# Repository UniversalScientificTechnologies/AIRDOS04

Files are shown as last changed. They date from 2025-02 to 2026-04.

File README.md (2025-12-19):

# AIRDOS04 - Specialized Cosmic Radiation Dosimeter for Airliners

AIRDOS04

The upgraded version of [AIRDOS02](https://github.com/UniversalScientificTechnologies/AIRDOS02) airborne detector. The instrument is designed primarily for the dosimetry of cabin crew and flight attendants of commercial flights. A detailed description of the use is in the [user manual](https://docs.dos.ust.cz/airdos/AIRDOS04).

## Design features 

  - Rechargeable accumulators integrated with data storage in the hot-swap module called [BATDATUNIT01](https://docs.dos.ust.cz/airdos/BATDATUNIT01)
    - The changeable module allows new possible features in the future, like GNSS-based position logging with a revised module 
  - One month of continuous logging for a single accumulator charge
  - Easy measurement activation by insertion of the BATDATUNIT module
  - Data download without special software (Mass storage media)
  - Continuously incrementing time marks (Unique logging time from every measurement) 

## Where to get it?

Purchase AIRDOS04, the open-source device designed for versatility, from [Universal Scientific Technologies s.r.o.](https://www.ust.cz). For sales inquiries, contact sale@ust.cz. Developed and maintained by UST, it comes with full commercial availability and dedicated technical support. The device is released under the GPLv3 license.

## Technical parameters

  * Silicon PIN diode detector with 44 mm³ detection volume
  * The effective number of energy channels is 886 ± 3
  * Deposited energy ranges from 36 keV to 7 MeV
  * Energy measurement resolution 15 ± 2 keV
  * Service interface:  USB-C connector (charging and data download)
  * Energy source: 18650 Li-ion cells conforms with [≤ 100 Wh / 2g restrictions](https://www.iata.org/contentassets/6fea26dd84d24b26a7a1fd5788561d6e/passenger-lithium-battery.pdf)
  * Radiation spectra integration time 10 s
  * Maintenance interval (data download, battery recharge)  30 days
  * Maintenance duration under 5 minutes
  * Approx size LxWxH 166 mm x 107 mm x 57 mm (two  of these should fit into the Aircraft printed manual bay)
  * Weight is 0.88 kg (With five accumulator cells in [BATDATUNIT01](https://github.com/mlab-modules/BATDATUNIT01))
  * Environmental operational conditions
    * Device protection: IP30 rating (fully assembled)
    * Operation temperature range: 0°C to 50°C (32°F to 122°F)
    * Operation humidity conditions: non-condensing, 20% to 80% RH

## Example data

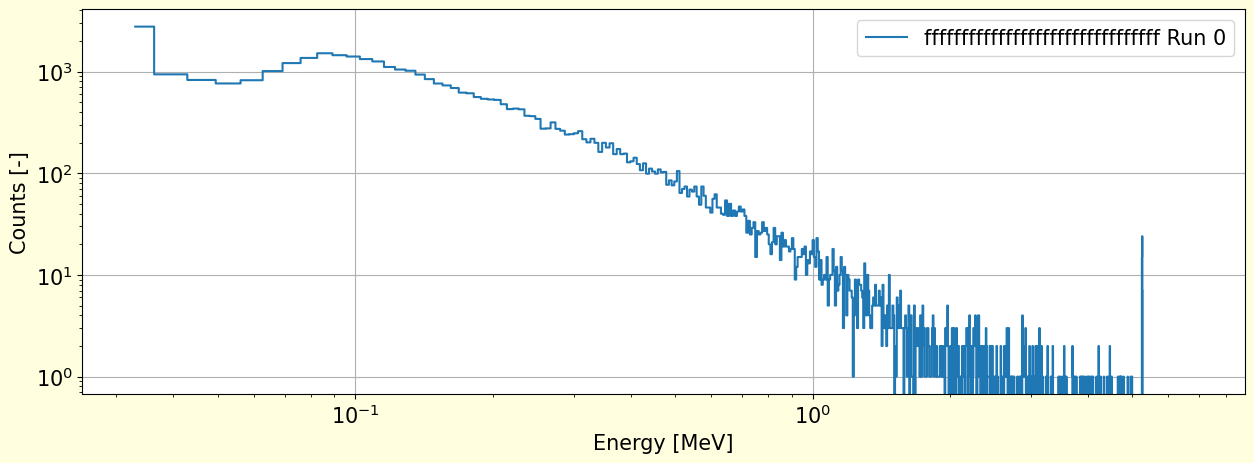
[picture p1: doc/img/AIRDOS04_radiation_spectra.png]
AIRDOS04 radiation spectra measurement


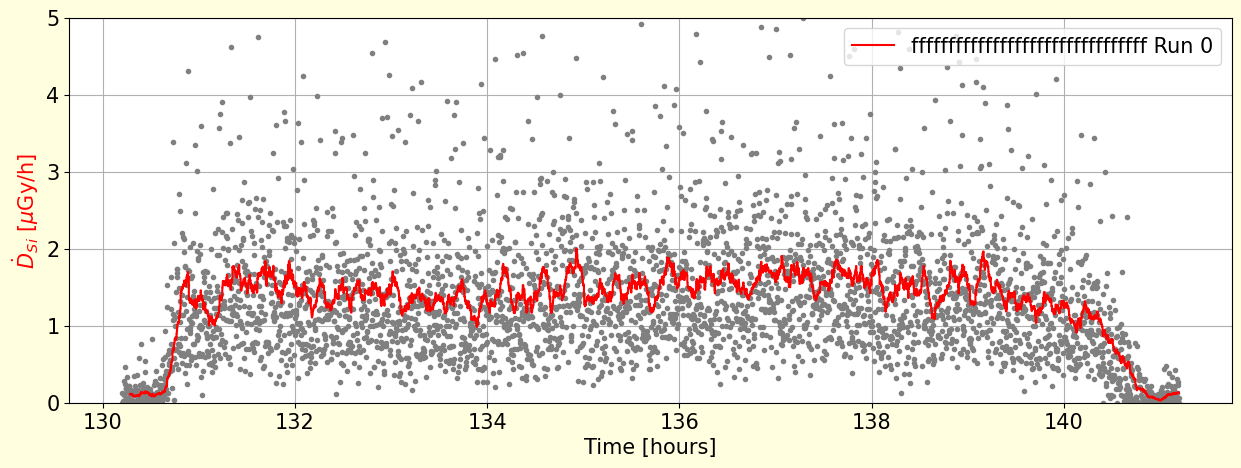
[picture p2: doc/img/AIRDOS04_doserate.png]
AIRDOS04 flight dose rate measurement


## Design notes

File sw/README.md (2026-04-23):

## airdoscontrol - AIRDOS04 command line utility

A utility designed to control the AIRDOS04 dosimeter from the [Unix command line](https://ubuntu.com/tutorials/command-line-for-beginners#1-overview). The  generic usage is the following

    sudo ./airdoscontrol [command] [options]

The airdos control is tested on the Ubuntu Linux distribution. However, it should work on any Unix-like OS like MacOS for example, although the installation procedure may differ in details. 

### Installation and prerequisites 

Download and save the [airdoscontrol](https://raw.githubusercontent.com/UniversalScientificTechnologies/AIRDOS04/AIRDOS04A/sw/airdoscontrol) somewhere in your Linux computer. Then make it executable by setting the executable flag on the downloaded file.   

    chmod u+x airdoscontrol

The airdos control uses [hidapi library](https://pypi.org/project/hidapi/) to communicate with AIRDOS, please check that hidapi is installed or install it by 

    sudo python3 -m pip install hidapi 

In case you do not want tu use [sudo](https://www.howtoforge.com/sudo-beginners-guide/) to run airdoscontrol every time, the utility needs correct [system access rights](https://linuxconfig.org/tutorial-on-how-to-write-basic-udev-rules-in-linux) to the hid device. To fix that create the file  `/etc/udev/rules.d/99-batdatunit.rules` in your Linux system with the following content:

```
ACTION=="add", SUBSYSTEM=="usb", ATTR{idVendor}=="0403", ATTR{idProduct}=="6030", OPTIONS+="ignore_device"
KERNEL=="hidraw*", ATTRS{idVendor}=="0403", MODE="6030", GROUP="plugdev"
SUBSYSTEM=="usb", ATTRS{idVendor}=="1209", ATTRS{idProduct}=="7aa0", GROUP="plugdev", MODE="0660"
SUBSYSTEM=="hidraw", ATTRS{idVendor}=="1209", ATTRS{idProduct}=="7aa0", GROUP="plugdev", MODE="0666"
```
Then use `sudo udevadm control --reload-rules && sudo udevadm trigger` command to update udev access rights. 

The user also needs to be a `plugdev` system group member. e.g. `sudo usermod -a -G plugdev $USER`

### Usage

Connect the AIRDOS04 to the computer using the USB-C to USB-A cable. NOTE: The BATDATUNIT01 should be inserted in AIRDOS04 for USB communication. 

#### Shutdown the AIRDOS Device

    airdoscontrol shutdown

This command would be straightforward with no additional options required. The AIRDOS is then powered off immediately after disconnection of the USB cable. It could be powered on only by pressing the button or plugging the USB-C cable back.  If the USB-C power is removed in the middle of writing to internal storage. It is theoretically possible to corrupt the filesystem on the internal SD card. Because in case of removing the USB-C cable after the shutdown command, the power is removed instantly, and the write cycle may not be completed.  The possibility of corruption could be easily avoided by unplugging the USB-C cable after the blink of the write indication LED. (In that case, there is integration time, e.g. 10 seconds to completely safely unplug the USB-C cable)

Please look in the [AIRDOS manual](https://docs.dos.ust.cz/airdos/AIRDOS04) for details.

#### Set internal RTC (Real-Time Clock)

    airdoscontrol set-rtc --time "YYYY-MM-DD HH:MM:SS"

Options could include specifying the time directly.

#### Set Pressure Thresholds

    airdoscontrol set-thresholds --min-pressure [value] --max-pressure [value]

Allows users to define minimum and maximum pressure values in hPa for flight detection.

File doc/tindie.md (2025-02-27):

AIRDOS04 is a cutting-edge airborne radiation dosimeter and spectrometer, designed to measure cosmic radiation and perform dosimetry in mixed ionizing radiation fields.

The development of AIRDOS04 is driven by the need for an advanced, user-friendly instrument capable of measuring cosmic radiation levels in aircraft. In the importance of radiation safety for flight crews and scientific research, we designed AIRDOS04 to enable the acquisition of data that contributes to understanding and managing space weather ionizing radiation exposure.

#### What makes it special?

AIRDOS04 is special because of its unique mix of technical sophistication and practical design:

  * **Advanced Detection Technology:** Utilizing a Silicon PIN diode and 470 ±3 energy channels, it delivers measurements across a wide deposited energy range (60 keV to 7 MeV). Its high resolution of 15 ±2 keV ensures detailed spectral resolution.
  * **Modular and Durable Design:** Encased in an aluminum box, interchangeable modules for data storage and power supply complement the core dosimeter detection unit. 
  * **User-Friendly Operation:** The instrument's design prioritizes ease of use, featuring automatic activation and LED indicators, straightforward battery level checks, and convenient USB-C charging.
  * **Environmental Adaptability:** Engineered to operate within a temperature range of 0°C to 50°C and an IP30 rating, AIRDOS04 is well-suited for various field conditions. Its size and weight are optimized for integration into aircraft manual bays, making it a perfect fit for aviation applications.
  * **Safety Focus:** The AIRDOS04 was developed with a strong emphasis on safety. It provides multiple levels of protection mechanisms to avoid an unintended situation and malfunctions.

#### Aircraft Fly-Crew Secondary Cosmic Ray Dosimeter

AIRDOS04 is designed for measuring mixed radiation fields caused by secondary cosmic rays at higher altitudes. Flight altitudes in the atmosphere are a typical example of a mixed radiation field.

Doserate measured on-board of an aircraft

#### Radiation spectra measurement

Because AIRDOS04 is also a spectrometer, it enables detailed ionizing radiation analysis by measuring the deposited energy in silicon. Here is an example of the captured spectra.

Radiation spectra measured by AIRDOS

## Technical parameters

The detector is equipped with indication LEDs that show the status of the device. AIRDOS contains LEDs indicating USB communication, and indicating the presence of a power supply. The internal accumulator status is indicated on the 8 LED bar.

  * Silicon PIN diode detector with at least 44 mm³ detection volume
  * The effective number of energy channels is 470 ±3
  * Deposited energy ranges from 60 keV to 7 MeV
  * Energy measurement resolution 15 ±2 keV
  * Service interface:  USB-C connector (charging and data download)
  * Optional GPS interface (with revised BATDATUNIT01)
  * Energy source: 18650 Li-ion cells conforms with [≤ 100 Wh / 2g restrictions](https://www.iata.org/contentassets/6fea26dd84d24b26a7a1fd5788561d6e/passenger-lithium-battery.pdf)
  * Radiation spectra integration time 10 s
  * Maintenance interval (data download, battery recharge)  30 days
  * Maintenance duration under 5 minutes
  * Approx size LxWxH 166 mm x 107 mm x 57 mm (two  of these should fit to Aircraft printed manual bay)
  * Weight is 0.88 kg (With five accumulator cells in BATDATUNIT01)
  * Environmental operational conditions
    * Device protection: IP30 rating (fully assembled)
    * Operation temperature range: 0°C to 50°C (32°F to 122°F)
    * Operation humidity conditions: non-condensing, 20% to 80% RH

## Shipment content:

  * AIRDOS04 sensor unit
  * BATDATUNIT01 - with 64 Wh Li-ion accumulators
  * Optional extra BATDATUNIT01 - Power and data storage modules

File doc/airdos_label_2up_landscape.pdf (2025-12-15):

# AIRDOS04 - DATA UNIT - service log

# | INSERTED | REMOVED | ERASED

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
Data module for AIRDOS04 detectors. Enter the date and time for each performed operation. Use this log to track the handling and servicing of the data module.
1) INSERTED – date and time when the module
is inserted into the detector
2) REMOVED – date and time when the module is removed from the detector
3) ERASED – date and time when stored data are erased from the module.

# AIRDOS04 - DATA UNIT - service log

# | INSERTED | REMOVED | ERASED

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
Data module for AIRDOS04 detectors. Enter the date and time for each performed operation. Use this log to track the handling and servicing of the data module.
1) INSERTED – date and time when the module
is inserted into the detector
2) REMOVED – date and time when the module is removed from the detector
3) ERASED – date and time when stored data are erased from the module.

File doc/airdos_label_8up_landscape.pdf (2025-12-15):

# AIRDOS04 - DATA UNIT - service log

# | INSERTED | REMOVED | ERASED | # | INSERTED | REMOVED | ERASED | # | INSERTED | REMOVED | ERASED | # | INSERTED | REMOVED | ERASED

1 | | | | 1 | | | | 1 | | | | 1
2 | | | | 2 | | | | 2 | | | | 2
3 | | | | 3 | | | | 3 | | | | 3
4 | | | | 4 | | | | 4 | | | | 4
5 | | | | 5 | | | | 5 | | | | 5
6 | | | | 6 | | | | 6 | | | | 6
7 | | | | 7 | | | | 7 | | | | 7
8 | | | | 8 | | | | 8 | | | | 8
9 | | | | 9 | | | | 9 | | | | 9
10 | | | | 10 | | | | 10 | | | | 10
11 | | | | 11 | | | | 11 | | | | 11
12 | | | | 12 | | | | 12 | | | | 12

Data module for AIRDOS04 detectors. Enter the date and time for
each performed operation. Use this log to track the handling and
servicing of the data module.
1) INSERTED – date and time when the module
is inserted into the detector
2) REMOVED – date and time when the module is removed from the detector
3) ERASED – date and time when stored data are erased from the module.

# AIRDOS04 - DATA UNIT - service log

Data module for AIRDOS04 detectors. Enter the date and time for each performed operation. Use this log to track the handling and servicing of the data module.
1) INSERTED – date and time when the module
is inserted into the detector
2) REMOVED – date and time when the module is removed from the detector
3) ERASED – date and time when stored data are erased from the module.

# AIRDOS04 - DATA UNIT - service log

Data module for AIRDOS04 detectors. Enter the date and time for each performed operation. Use this log to track the handling and servicing of the data module.
1) INSERTED – date and time when the module
is inserted into the detector
2) REMOVED – date and time when the module is removed from the detector
3) ERASED – date and time when stored data are erased from the module.

# AIRDOS04 - DATA UNIT - service log

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

# AIRDOS04 - DATA UNIT - service log

# | INSERTED | REMOVED | ERASED | # | INSERTED | REMOVED | ERASED | # | INSERTED | REMOVED | ERASED | # | INSERTED | REMOVED | ERASED

1 | | | | 1 | | | | 1 | | | | 1
2 | | | | 2 | | | | 2 | | | | 2
3 | | | | 3 | | | | 3 | | | | 3
4 | | | | 4 | | | | 4 | | | | 4
5 | | | | 5 | | | | 5 | | | | 5
6 | | | | 6 | | | | 6 | | | | 6
7 | | | | 7 | | | | 7 | | | | 7
8 | | | | 8 | | | | 8 | | | | 8
9 | | | | 9 | | | | 9 | | | | 9
10 | | | | 10 | | | | 10 | | | | 10
11 | | | | 11 | | | | 11 | | | | 11
12 | | | | 12 | | | | 12 | | | | 12

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

# AIRDOS04 - DATA UNIT - service log

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

# AIRDOS04 - DATA UNIT - service log

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

# AIRDOS04 - DATA UNIT - service log

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

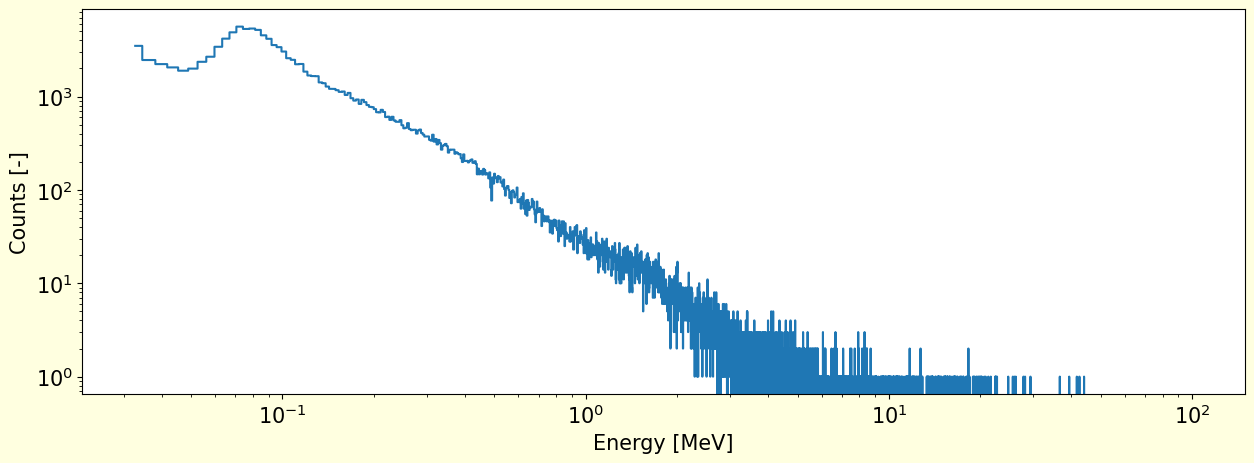
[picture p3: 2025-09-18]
doc/img/AIRDOS04_CERF_spectra.png

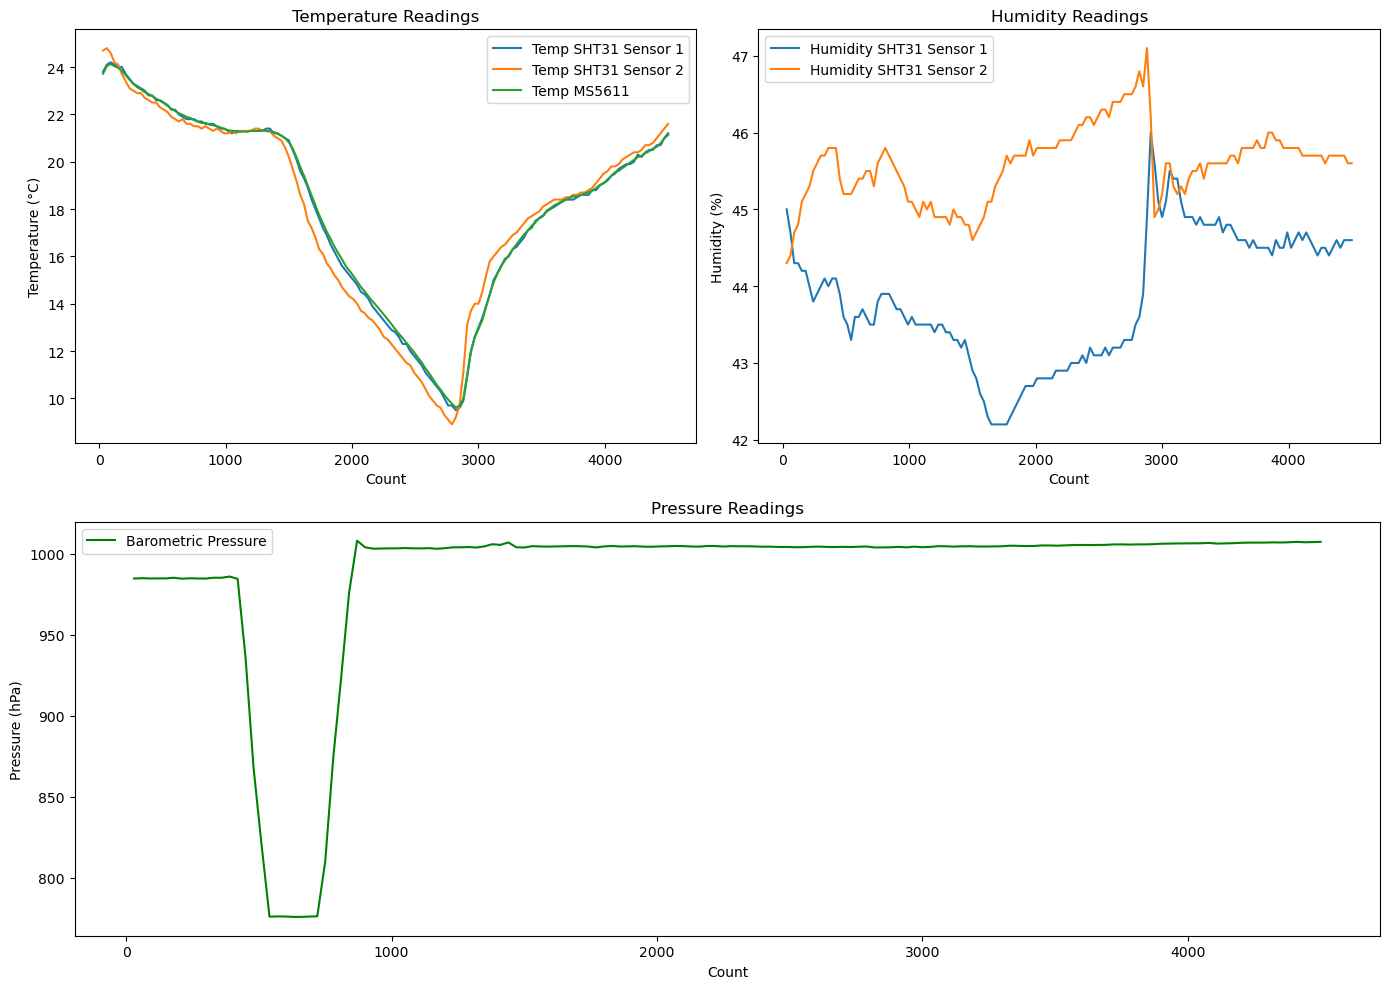
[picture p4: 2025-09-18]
doc/img/AIRDOS04_flight_environment.png

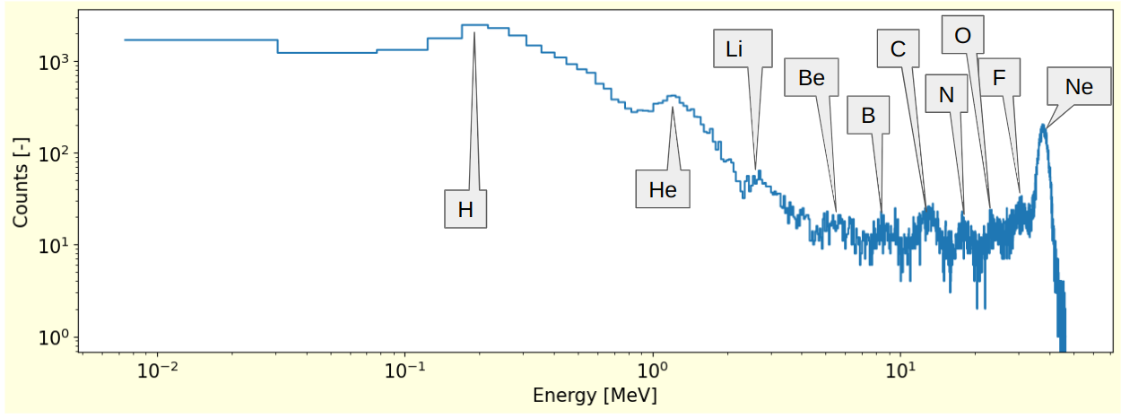
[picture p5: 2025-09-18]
doc/img/AIRDOS04_HIMAC_fragments.png

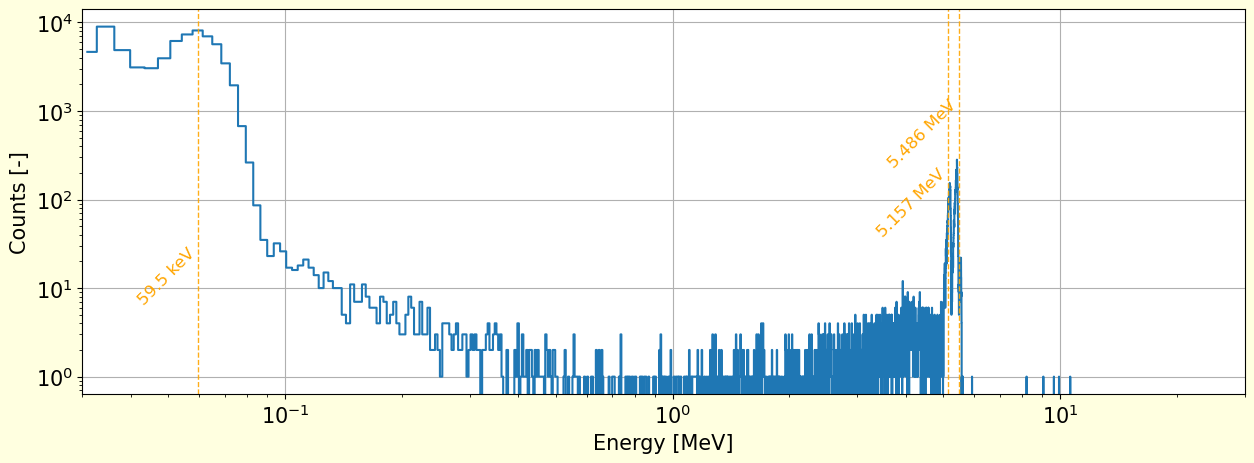
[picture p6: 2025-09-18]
doc/img/AIRDOS04_Am-241_Pu-239.png

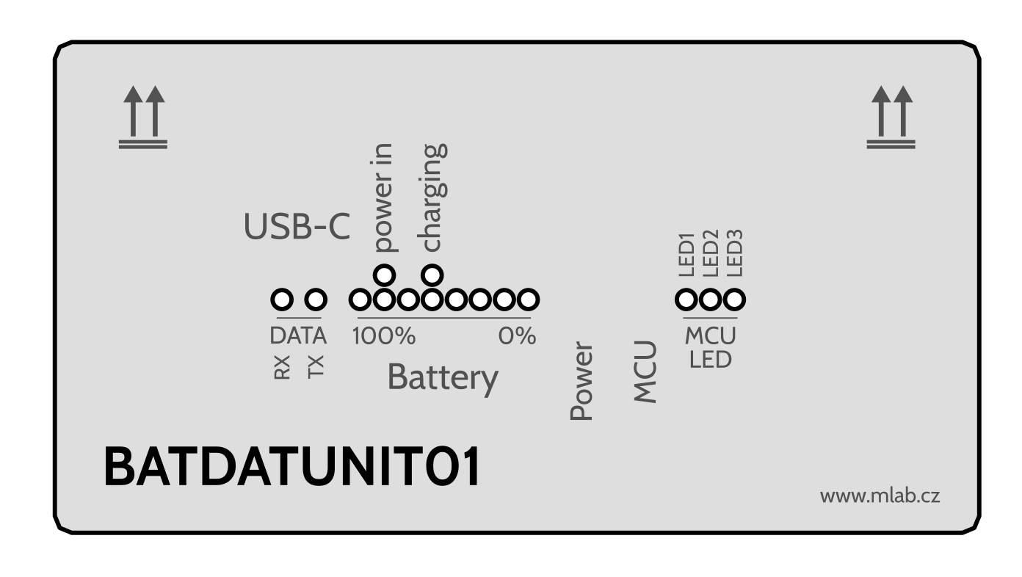
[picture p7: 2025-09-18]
hw/cad/svg/airdos04_sticker.png

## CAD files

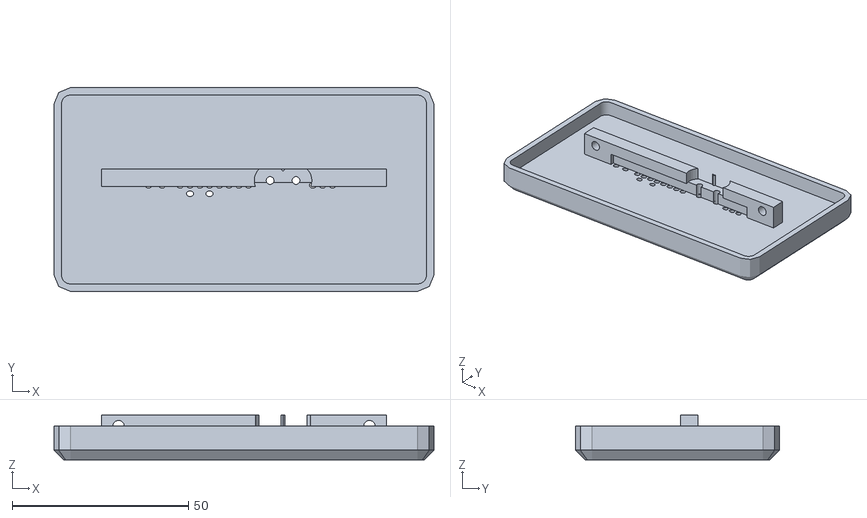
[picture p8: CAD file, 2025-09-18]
hw/cad/STL/assembly_front.stl
107.7 x 57.7 x 12.6

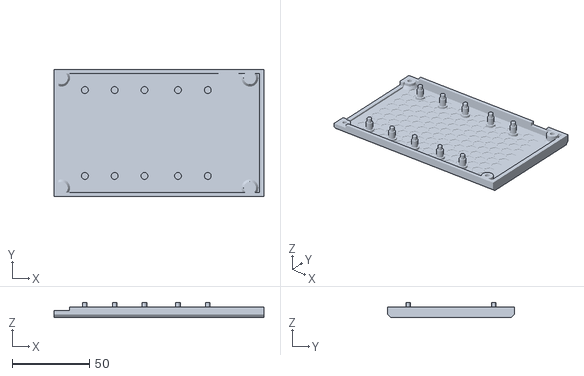
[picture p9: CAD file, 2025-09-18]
hw/cad/STL/assembly_case.stl
136.0 x 82.0 x 10.0

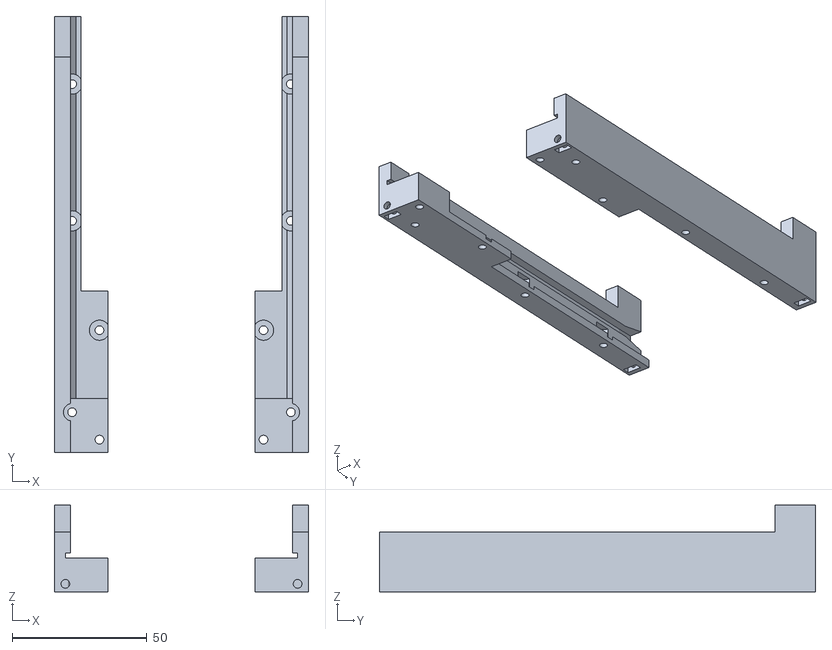
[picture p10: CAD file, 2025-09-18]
hw/cad/STL/assembly_rails.stl
94.5 x 162.0 x 32.3

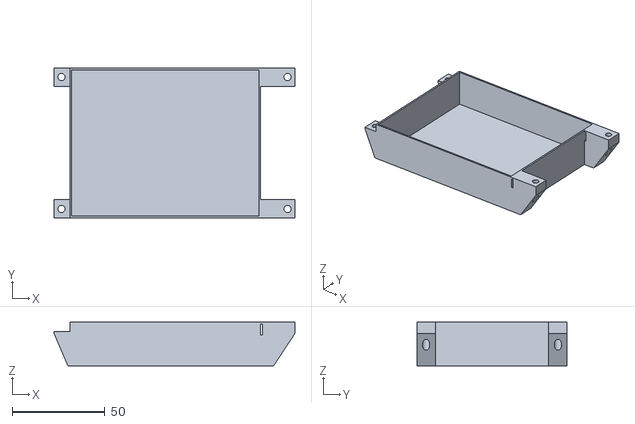
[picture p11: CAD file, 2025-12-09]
hw/cad/STL/battery_cover.stl
130.0 x 81.1 x 23.5

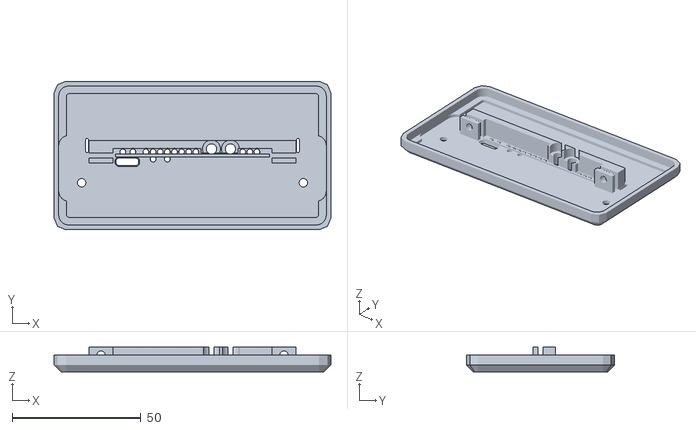
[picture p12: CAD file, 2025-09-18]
hw/cad/STL/printplate_front_cover.stl
107.7 x 57.7 x 9.62

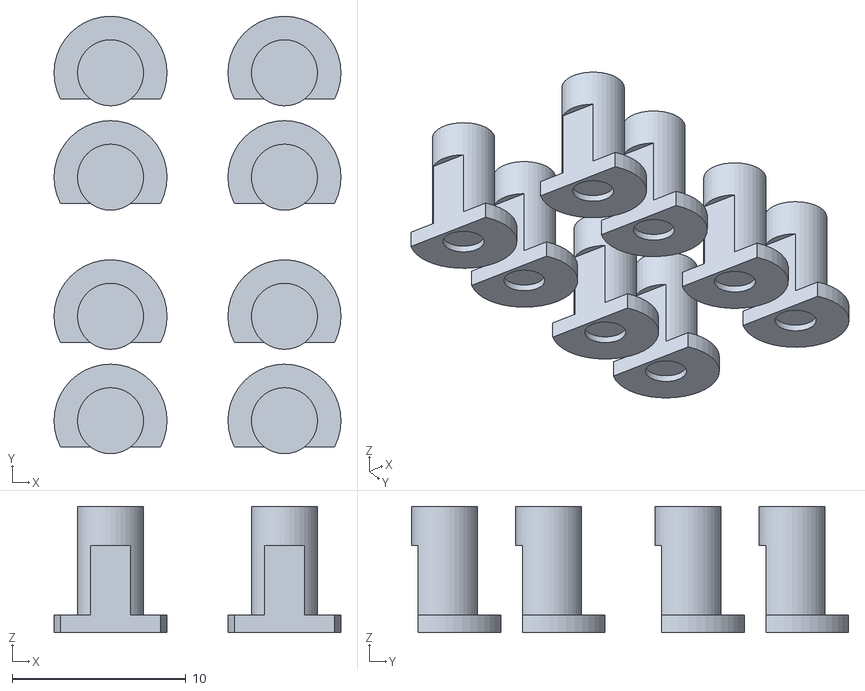
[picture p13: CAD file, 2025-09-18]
hw/cad/STL/printplate_button.stl
16.5 x 25.1 x 7.25

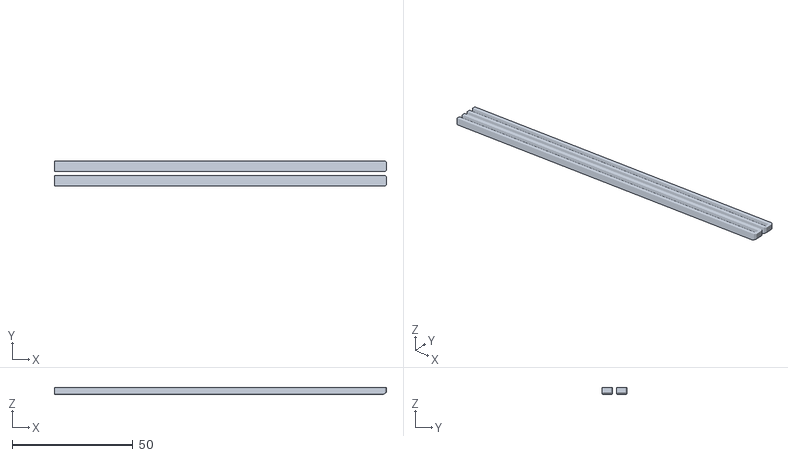
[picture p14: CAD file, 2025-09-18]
hw/cad/STL/printplate_pcbedge.stl
137.6 x 10.5 x 3.00

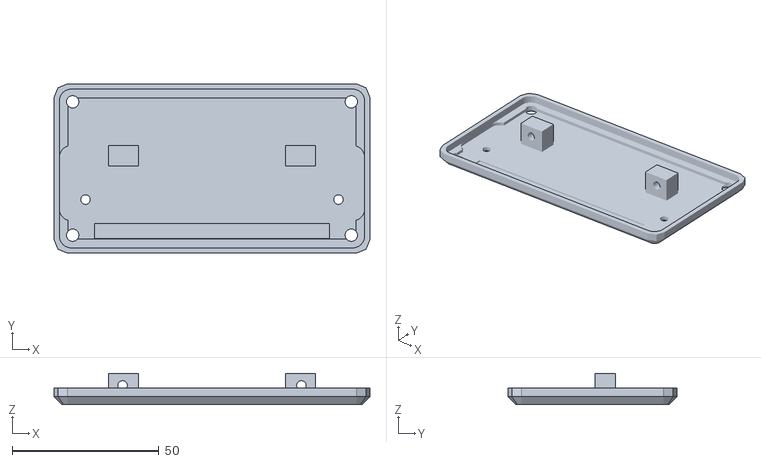
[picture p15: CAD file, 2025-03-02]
hw/cad/STL/printplate_rear_cover.stl
107.7 x 57.7 x 10.6

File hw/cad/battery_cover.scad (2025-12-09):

module battery_case(){

battery_length = 101;
battery_width = 79;
battery_height = 22;
wall_around = 1;
wall_top = 1.5;


beam_length = 130;
beam_thickness = 10;
front_offset = 6;

screw_distance = 10.16*12;


difference(){
    translate([0, 0, battery_height/2-wall_top/2]) cube([battery_length+wall_around*2, battery_width+wall_around*2, battery_height+wall_top], center=true);
    translate([0, 0, battery_height/2]) cube([battery_length, battery_width, battery_height], center=true);
}


offset = 5;

for(y=[-0.5, 0.5]) translate([0, y*10.16*7, 0]) difference(){
    hull(){
        translate([offset, 0, battery_height-3]) cube([beam_length, beam_thickness, 6], center=true);
        
        
        translate([3, 0, 0.05]) cube([battery_length+2*wall_around+5+3, beam_thickness, 0.1+wall_top*2], center=true);

    }
    translate([0, 0, battery_height/2]) cube([battery_length, battery_width, battery_height], center=true);
    
    translate([-20, 0, battery_height*1.5-5]) cube([battery_length, battery_width, battery_height], center=true);

    translate([battery_length/2+wall_around+0.5, 0, battery_height-4])
        cube([1, 100, 6], center=true);

    for(x=[0.5, -0.5]) translate([offset+screw_distance*x, 0, 0]){
        cylinder(d=3.9, h=50, center=true, $fn=50);
        // cylinder(d=3.8, h=30, center=true, $fn=50);

    }
}


}



battery_case();

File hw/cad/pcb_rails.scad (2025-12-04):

pcb_width = 85.86 + 0.4;
pcb_thickness = 1.6+0.2;
pcb_above_ground = 12.6; 

pcb_rail_thickness = 1.6+1.5+1.5+0.1;
pcb_rail_depth = 1.5;

albase_length = 162;
box_width = 95-0.5;

flange_width = 20;
flange_th = 3.5;
mounting_holes_distance = 3*10.16;

M3_screw_diameter = 3.25;
M3_nut_diameter = 6.4;


module pcb_edge(){
    difference(){
        translate([0, 0, 1.5]) cube([136.6+1, pcb_rail_thickness-0.2, 3], center=true);
        translate([-1, 0, 2+pcb_rail_depth-0.1]) cube([136.6+1, 1.65, 4], center=true);
        translate([0, pcb_rail_thickness/2, 0]) rotate([0, 90, 0]) cylinder(d=1, h=150, center=true, $fn=4);
        translate([0, -pcb_rail_thickness/2, 0]) rotate([0, 90, 0]) cylinder(d=1, h=150, center=true, $fn=4);
        translate([136.6/2+0.75, pcb_rail_thickness/2, 0.8]) rotate([0, 0, 0]) cylinder(d=2, h=5, center=true, $fn=4);
        translate([136.6/2+0.75, -pcb_rail_thickness/2, 0.8]) rotate([0, 0, 0]) cylinder(d=2, h=5, center=true, $fn=4);
        translate([136.6/2+0.75, -pcb_rail_thickness/2, -1]) rotate([90, 0, 0]) rotate([0,0,-15]) cylinder(d=5, h=10, center=true, $fn=4);
    }

}


//pcb_edge();

module rail(){
    
    difference(){
        union(){
            translate([box_width/2-6, -albase_length/2, 0]) cube([6, albase_length, pcb_above_ground+pcb_rail_thickness+5]);
            
            translate([box_width/2-6, albase_length/2-15, 0]) cube([6, 15, pcb_above_ground+pcb_rail_thickness+5+10]);
            
            translate([box_width/2-flange_width, -(albase_length)/2, 0]) cube([flange_width, 60, flange_th]);
            translate([box_width/2-flange_width, -(albase_length)/2, 0]) cube([flange_width, 20, pcb_above_ground]);
            translate([box_width/2-8, -(albase_length)/2, 3.5]) rotate([0, 45, 0]) cube([4, albase_length, 4]);
            
            translate([box_width/2-10, -albase_length/2, 0]) cube([10, albase_length, flange_th]);
            
         
        
        }
                
        // for(m=[0, 1]) mirror([0, m, 0]) {
        for(m=[]) mirror([0, m, 0]) {
            translate([pcb_width/2, -albase_length/2+15, 3]) rotate([90, 0, 0]) cylinder(d=M3_screw_diameter, h=20, $fn=60);
            
            hull(){
                translate([pcb_width/2, -albase_length/2+5, 3]) rotate([90, 0, 0]) cylinder(d=M3_nut_diameter, h=3, $fn=6);
                translate([pcb_width/2, -albase_length/2+5, -3]) rotate([90, 0, 0]) cylinder(d=M3_nut_diameter, h=3, $fn=6);
            }
        }
        
        
        for(m=[0,1]) mirror([0, m, 0]) {
            translate([pcb_width/2, -albase_length/2+15, 3]) rotate([90, 0, 0]) cylinder(d=3.8, h=20, $fn=60);
            translate([pcb_width/2, -albase_length/2+2, 3]) rotate([90, 0, 0]) cylinder(d=8, h=2, $fn=60);
        }
    
    translate([0, -(albase_length+1)/2, pcb_above_ground])
        cube([pcb_width/2, albase_length+1, pcb_thickness]);
    translate([0, -(albase_length-40)/2, pcb_above_ground-(pcb_rail_thickness-pcb_thickness)/2])
        cube([pcb_width/2+pcb_rail_depth, albase_length, pcb_rail_thickness]);
    
    hull(){
        translate([0, (albase_length)/2-10, pcb_above_ground-(pcb_rail_thickness-pcb_thickness)/2])
            cube([pcb_width/2+pcb_rail_depth, 10, pcb_rail_thickness]);
        translate([0, (albase_length)/2, pcb_above_ground-(pcb_rail_thickness-pcb_thickness)/2-2])
            cube([pcb_width/2+pcb_rail_depth+2, 10, pcb_rail_thickness+4]);
    }
    
    for(y = [5, 0], x=[10.16]) translate([mounting_holes_distance+x, (y+0.5)*10.16, -0.1]) {
        cylinder(d = M3_screw_diameter, h=5, $fn=30);
        translate([0, 0, 2]) rotate([0, 0, 30]) cylinder(d=7.5, h=7.5, $fn=60);
        }
        
    for(y = [-7], x=[10.16]) translate([mounting_holes_distance+x, (y+0.5)*10.16, -0.1]) {
        cylinder(d = M3_screw_diameter, h=20, $fn=30);
        translate([0, 0, pcb_above_ground+0.1]) cylinder(d = 6.5, h=20, $fn=30);
        }
    
    for(y = [-8+4], x=[0]) translate([mounting_holes_distance+x, (y+0.5)*10.16, -0.1]) {
        cylinder(d = M3_screw_diameter, h=30, $fn=30);
            translate([0, 0, 1.5]) rotate([0, 0, 30]) cylinder(d=M3_nut_diameter, h=3, $fn=6);
        }
        for(y = [-8], x=[0]) translate([mounting_holes_distance+x, (y+0.5)*10.16, -0.1]) {
        cylinder(d = M3_screw_diameter, h=30, $fn=30);
        //translate([0, 0, 3]) rotate([0, 0, 30]) cylinder(d=6.5, h=3, $fn=60);
        }
    }
    

}



rail();
//mirror([1, 0, 0]) rail();


batdat_case_length = 136;
batdat_case_width = 82;
batdat_case_thickness = 7;

screw_shift = 12.0-10.16/2-4.83;

sn_view_position_x = 10.16*6-screw_shift+3.27;

module bottom_case(){

    difference(){
        translate([0, 0, batdat_case_thickness/2])
            cube([batdat_case_length, batdat_case_width, batdat_case_thickness], center=true);
       
        // pojistky
        translate([0, 0, 6]) cube([batdat_case_length-40, batdat_case_width-3, batdat_case_thickness], center=true);
        
        
        // vyrez pro programovaci konektor
        translate([20-3, -10-4.5, -2])
            cube([6, 9, 10]);

        
        // montazni srouby
        for(x=[-1, 1], y=[-1, 1])
            translate([x*10.16*6-screw_shift, y*10.16*3.5+0, -0.1]) {
            translate([0, 0, 3.2])
                cylinder(d=M3_screw_diameter, h=10, $fn=50);
            cylinder(d=6.6, h=3, $fn=6);
        }
        
        
        // pro senzory
        translate([45, batdat_case_width/2, batdat_case_thickness]) cube([13, 10, 5], center=true);
        
        // honeycomb
        translate([0, 3, 0.4]) intersection(){
            for(x=[-8:7], y=[-4:3])
               translate([x*7, y*8+(x%2==0? 4:0), 0])
                    cylinder(d=7.5, h=10, $fn=6);
        }
        
        
        // srazeni spodni hrany
        for(y=[-1, 1])
            translate([0, y/2*batdat_case_width, 0])
                rotate([0, 90, 0]) 
                    cylinder(h=batdat_case_length, r=2, center=true, $fn=4);

        // hlavni odebrani vyplne
        difference(){
            union(){
                translate([0, 0, 5+0.75]) 
                    cube([130, 77, 10], center=true);
                translate([-10, 0, 2.5+batdat_case_thickness-5]) 
                    cube([130, 62, 5], center=true);
                translate([-batdat_case_length/2, 0, 2.5+batdat_case_thickness-2.2]) 
                    cube([20, 100, 5], center=true);
            }
        
    
        
        // Okenko pro SN
        //translate([sn_view_position_x, 0, 0]) cube([8+1.4, 45+1.4, 20], center=true);
            
            
            
        for(x=[1], y=[-1, 1]) translate([x*10.16*6-screw_shift, y*10.16*3.5+0, -0.1]) {
            cylinder(d=8, h=10, $fn=60);
            cylinder(d1=12,d2=8, h=3, $fn=60);
        }
        
        
            
        for(x=[-1], y=[-1, 1]) translate([x*10.16*6-screw_shift, y*10.16*3.5+0, -0.1]) {
            cylinder(d=8, h=5+2.1-2.2, $fn=60);
            cylinder(d1=12,d2=8, h=3, $fn=60);
        }
            
        }
        
        
        
        // Okenko pro SN
        //translate([sn_view_position_x, 0, 0]) cube([8, 45, 20], center=true);
            
    
    
    }
    
    // Podperne sloupky
   for(y=[-31.6, -12.3, 9.4, 28.7, 48], x=[-0.5, 0.5]) translate([-y, x*55.6, 0]){
    
        cylinder(d = 6.5, h=2, $fn=30);
        cylinder(d = 4.5, h=batdat_case_thickness, $fn=30);
        cylinder(d = 3, h=batdat_case_thickness+3, $fn=30);
    }
    
    
        translate([20-3, -10-4.5, 0])
            difference(){
                translate([-1, -1, 0]) cube([6+2, 9+2, 5]);
                cube([6, 9, 5]);
            }
    
}

//bottom_case();




box_outer_w = 103+0.5;
box_outer_h = 53+0.5;
box_pcb_shift = 10;


module front_cover_empty(){



    difference(){
        union(){
            minkowski(){
                sphere(d=10, $fn=8);
                translate([0, 0, 5]) cube([box_outer_w+5-10, box_outer_h+5-10, 4], center=true);
            }
    
        }
        
    
    translate([0, 0, 5+5]) cube([200, 200, 10], center=true);
        
    translate([0, 0, 1.25]) minkowski(){
        cylinder(d=8, h=10, $fn=30);
        cube([box_outer_w-8+0.6, box_outer_h-8+0.6, .1], center=true);
    }
    
    
    // Vyrez pro celou sirku ALBASE
    translate([0, -5, 0]) minkowski(){
        cylinder(d=8, h=10, $fn=30);
        cube([box_outer_w-8+0.6, 25-8+0.6, .1], center=true);
    }
    
    
    translate([0, 0, 0]) minkowski(){
        cylinder(d=2, h=10, $fn=30);
        cube([box_outer_w-8+0.6, box_outer_h-8+0.6, .1], center=true);
    }
    
       
    
    }
}


leds_positions_top = [25.07, 22.3, 19.52, 1.3, -1.46, -4.25, -7, -9.78, -12.53, -15.3, -18.1, -23.2, -27.1];
leds_positions_bottom = [-9.78, -15.3];
leds_button = [7.4, 14.75];

module front_cover(){

    difference(){

        union(){
            front_cover_empty();
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

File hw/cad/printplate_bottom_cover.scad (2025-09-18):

use<pcb_rails.scad>;

bottom_case();

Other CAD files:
hw/cad/STL/printplate_rails.stl
hw/cad/STL/printplate_bottom_cover.stl
hw/cad/STL/pcb_rails.stl
hw/cad/printplate_front_cover.scad

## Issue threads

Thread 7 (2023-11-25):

Implement accumulator charging over USB-C

kaklik, 2023-11-25:
@roman-dvorak  to má nějak rozchozené, se sadou I2C příkazů, kterou vyexportuje z pythonu. To se pak překopíruje přímo do ardiuna

kaklik, 2023-12-17:
Současné řešení kdy je dobíječka částečně ovládána z MCU je dostatečně funkční.

Closed 2023-12-17.

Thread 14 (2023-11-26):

MISO/MOSI change of direction

kakl, 2023-11-26:
Na PCB s diodou jsou spatne zapojeny prevodniky napetovych urovni. Pripojeni neodpovida smeru signalu MOSI a MISO.

kaklik, 2023-11-26:
Tohle je redundantní k: https://github.com/kaklik/USTSIPIN03/issues/4

Closed 2023-11-26.

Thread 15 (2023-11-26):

OPA power crossed

kakl, 2023-11-26:
Na PCB s diodou je prohozeno napajeni u nabojoveho zesilovace s OPA.

kaklik, 2023-11-26:
Redundantní k tomuhle: https://github.com/kaklik/USTSIPIN03/issues/6

Closed 2023-11-26.

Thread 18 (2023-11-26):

Too transparent PCB

kakl, 2023-11-26:
PCB s diodou je prilis prusvitne. Pod diodu je treba dat neprusvitnou podlozku. Treba cernou elektrikarskou pasku.

kaklik, 2023-11-26:
To řešení s černou izolační páskou jsi testoval, že funguje?
Jinak je to redundatní k tomuhle: https://github.com/kaklik/USTSIPIN03/issues/2

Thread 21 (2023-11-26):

Molex geometry

kakl, 2023-11-26:
Je treba upravit PCB s procesorem, aby do nej sel zastrcit Molex konektor. Musi se preroutovat cesty 5V a 3V3, aby na PCB mohl byt vyrez na konektor.

kaklik, 2023-11-26:
Tohle je už opravené v revizi B: https://github.com/mlab-modules/BATDATUNIT01/tree/BATDATUNIT01B

Closed 2023-11-26.

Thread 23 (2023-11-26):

SD card reader oscillator selection

kakl, 2023-11-26:
SD card reader nefunguje bez krystalu.

kaklik, 2023-11-26:
Oscilátor je na nové revizi už přidaný. Spíš je nutné vybrat vhodný typ, který má nízkou spotřebu ve vypnutém stavu. Výběr oscilátorů pro frekvenci 19,2MHz ale [není moc velký](https://cz.mouser.com/c/passive-components/frequency-control-timing-devices/oscillators/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)..

- ~~https://www.tme.eu/cz/details/19.20m-iqxo-542/krystalove-generatory-smd/iqd-frequency-products/lfspxo056188cutt/~~ velmi malé pouzdro a nemůže být napájen z 3.3V.
- https://cz.mouser.com/ProductDetail/SiTime/SiT1602BI-13-XXS-19.200000D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

kaklik, 2023-11-26:
Zkusit objednat i jiné frekvence oscilátoru.

kaklik, 2023-11-27:
> Zkusit objednat i jiné frekvence oscilátoru.

Tak z jiných frekvencí oscilátorů bude zítra k dispozici akorát 12MHz.

Closed 2023-11-27.

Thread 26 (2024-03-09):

Saturation of the analog front-end

kaklik, 2024-03-09:
V analogové části dochází zatím z neznámého důvodu k saturaci o více jak 100 kanálů dříve, než by mělo.

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

Vyřešení této nedokonalosti by umožnilo lépe využít dynamický rozsah ADC a tím i zvětšit měřený energetický rozsah.

kaklik, 2025-05-10:
Resolved by improved Analog front-end.

Closed 2025-05-10.

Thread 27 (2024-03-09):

Geiger like Sound output

kaklik, 2024-03-09:
Bylo by užitečné, kdyby detektor uměl vytvářet cvakání, podobně jako je známé z GM detektoru.  Mělo by to tyhle výhody:

- Jde snadno demonstrovat k čemu je detektor dobrý (je to forma výstupu, kterou zná hodně lidí)
- Bylo by poznat, že detektor funguje správně. (Například když se k nemu přiblíží uranová sklenička)
- Je to marketingově výhodná vlastnost

Takovou funkci by pravděpodobně mělo být možné nějakým způsobem zapnout a vypnout. Nepovažoval bych za praktické, kdyby to vyžadovalo úplně speciální firmware (je tu ale omezení, že cvakání určitě bude žrát procesorový čas a  tím zřejmě ovlivňovat mrtvou dobu)
Vypínání, nebo zapínání takové vlastnosti by šlo například implementovat držením tlačítka na předním panelu.  Nebo případně zápisem na nějakou adresu EEPROM, kde si toho procesor po zapnutí všimne.

kaklik, 2024-03-29:
Experimentálně jsem zkusil cvaknutí přidat do firmware.  Taková implementace má několik zásadních omezení:

- Cvaká potichu (ke zvýšení hlasitosti by bylo potřeba prodloužit délku pulzu v high. To ale znamená zavést delay. Delay ale zavede i mrtvou dobu)
- Cvaká pořád. To kromě zvýšené spotřeby může být v důsledku i otravné
- Cvakání zvýšilo mrtvou dobu obsluhy ADC minimálně dvěma dalšími instrukcemi.

https://github.com/UniversalScientificTechnologies/AIRDOS04/assets/1194177/c7933e6b-a8ef-42ea-8abe-32477d7e57e6

roman-dvorak, 2024-04-30:
Mám k té implementaci poznámky, u arduina je známé, že jeho výchozí metody pro digitalWrite zabírají relativně hodně instrukcí, protože dělá věci, jako že kontroluje existenci pinu a další (pro tento účel ne úplně potřeblé) věci. Zřejmě to souvisí s tím, aby kód byl snadno přenositelný mezi procesory, což aktuálně není náš požadavek.

Více informací je např zde:  https://roboticsbackend.com/arduino-fast-digitalwrite/

Kde zároveň uvádí, že tato operace trvá 3.4 us.

V případě přímého zápisu do registru nastavující tento pin je to značně rychlejší. Pouze při zápisu se lze dostat na 0.19 us. Což my nemůžeme nastavovat celou sběrnici ale měnit jeden pin. To podle stejného odkazu zabere 0.26 us.

Vím, že existují knihovny, které obsahuí něco jako "FastDigitalWrite()" funkci. Je na zvážení, jestli využívat tuto funkci z nějakých cknihoven a nebo používat přímo zápis do registru sbernice.

Pak mne napadlo, že by bylo možná užitené místo bzučáku používat LEDku pro rychlou diagnostiku stavu detektoru (nebo možnost volby)

Vypínáni a nastavování této funkce bych si představoval pomocí [dosview[(https://github.com/UniversalScientificTechnologies/dosview/) nastavením dohodnutých bitů do eeprom.

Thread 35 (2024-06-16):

Analogue part is disconnected dunig PC-HID mode

roman-dvorak, 2024-06-16:
Když se AIRDOS připojí k PC ve složeném stavu, tak je vypnuté napájení nebo I2C vypínač analogové části. Díky tomu nelze například zjistit z počítače SN airdosu..

kaklik, 2024-06-17:
To je ale myslím správně že je to vypnuté.  Vyřešit by to šlo zřejmě jen tím, že MCU bude nějak požádán o to, aby napájení zapnul a zpřístupnil I2C.  Vznikne tak ale potíž s tím, že během měření to v takovém stavu nesmí zůstat.
Nejlogičtější řešení pro takovou situaci myslím je nějaký výrobní, nebo testovací firmware, který takové postupy umožní, ale zároveň nebude určen pro měření.

roman-dvorak, 2024-06-22:
To může být vyřešené tak, že MCU si bude kontrolovat, jestli je I2C switch přepnutí k procesoru nebo k USB. V případě, že je přepnutý k USB, tak stejně nemůže probíhat měření, protože chybí některá data. Obslužné nástroje by tak počkaly na konec expozice a pak by MCU umožnil k I2C periferiím v analogové části.

Tento stav by neměl trvat déle než jednu expozici. Po nějakém timeoutu (pokud mu to nebude navráceno) by si to měl převzít zpět a možná provést re-inicializaci některých senzorů.

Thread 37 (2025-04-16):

RTC time reset for batterry-less variant

kaklik, 2025-04-16:
Bezbateriová verze BATDATUINT01 má momentálně tu nepříjemnou vlastnost že při výpadku napájení se resetuje její čas. V důsledku toho všechna měření provedená tímto způsobem začínají od nuly.

Řešením by zřejmě bylo na VBAT pin RTC obvodu připojit nějaký záložní zdroj. Možnosti podle datasheetu obvodu jsou:

- Další akumulátor (asi NiMH, aby nenarušoval absenci lithiových článků v zařízení)
- Knoflíková baterie
- Kondenzátor

Požadavkem je aby zařízení spolehlivě vydrželo 14 dní bez napájení, aniž by ztratilo informaci o reálném čase.

kaklik, 2025-04-16:
Vypadá to, že tento problém nelze řešit superkapacitorem. Nenašel jsem žádný, který by se do zařízení vešel a zároveň by dovedl zálohovat více jak desítky hodin.

Použití akumulátorového článku je nepraktické, protože by vyžadovalo přidání nějakého dobíjecího obvodu.

Zbývá použít obyčejnou knoflíkovou baterii (nejspíš CR2032) která by zálohování času vyřešila.

kaklik, 2025-04-24:
Zjistil jsem, že zřejmě existují [superkondenzátory v pouzdru 18650](https://www.alibaba.com/product-detail/Capacitor-supplier-4-2v2100f-supercapacitor-lithium_1600581288068.html), ale nejdou moc koupit a jejich parametry jsou nejasné. Je možné, že to reálně jsou nějaké staré typy Li-ion článků. Experimentálně by je ale šlo vyzkoušet.

Jako nejlepší řešení stále vypadá, že je použití malé baterie na spodní straně PCB.  Možná, že by nebyla ani nutná velikost CR2032, ale nějaká menší. Například na Pixhawk PAB autopilotech je jakási [malá baterie](https://arkelectron.com/product/arkv6x-iim-42653/) naletovaná přímo na PCB.

kaklik, 2025-05-10:
Vyřešeno přidáním baterie CR2032

Closed 2025-05-10.

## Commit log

2025-02-09 tests with 1st prototype
2025-02-27 Prepared testing print for front cover.
    [pcb_rails.scad, printplate_front_cover.scad, printplate_front_cover.stl]
2025-02-27 Improve tolerances. Attempt to fix #25
    [pcb_rails.scad, printplate_front_cover.3mf, printplate_front_cover.stl]
2025-02-28 Reduce microphone effect. #24 Fix button tolerances #25
    [pcb_rails.scad, printplate_button.stl, printplate_front_cover.3mf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]
2025-03-02 clicks by button
2025-08-27 CAD files improvement
    [bat_bottom.3mf, battery_cover.scad, battery_cover.stl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]
2025-08-27 Switch bootloader to UART1.
2025-08-27 Switch bootloader to UART1., extended build
2025-08-27 Switch Urboot bootloader to Optiboot.
2025-08-27 Switch Urboot bootloader to Optiboot., extended build
2025-08-27 attemt to change uart settings for bootloader.
2025-08-27 Revert "attemt to change uart settings for bootloader."
    This reverts commit 52294f35408dc1573d1a2c31b09f5826aeacbf8d.
2025-08-27 Revert "attemt to change uart settings for bootloader.", extended build
2025-09-01 Repository cleanup.
    [assembly_case.stl, assembly_front.stl, assembly_rails.stl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]
2025-09-17 Modify battery charger configuration in AIRDOS04X
2025-09-17 Modify battery charger configuration in AIRDOS04X, extended build
2025-09-18 disable charger as note
2025-12-04 zatavovaci matice
    [battery_cover.scad, pcb_rails.scad]
2025-12-09 Update battery cover geometry
    [battery_cover.scad, battery_cover.stl]
2025-12-15 Add datasheets for PCF85263A RTC and TI battery presence detection
2025-12-16 Detect battery presence and disable charger when absent
2025-12-16 Detect battery presence and disable charger when absent, extended build
2025-12-16 Build AIRDOS04 firmware with battery presence detection
2025-12-16 Fix USB reader mode to not exit when battery absent
2025-12-16 Fix USB reader mode to not exit when battery absent, extended build
2025-12-16 Simpler charger function
2025-12-16 Add AIRDOS04.ino changes to battery presence detect feature
2025-12-16 Add AIRDOS04.ino changes to battery presence detect feature, extended build
2025-12-16 Add AIRDOS04.ino changes to battery presence detect feature, extended build, extended build
2026-04-23 Update README.md
    Update usb device rules.
